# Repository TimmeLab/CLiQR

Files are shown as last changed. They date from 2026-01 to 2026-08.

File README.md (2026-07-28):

# CLiQR - Capacitive Lick Quantification in Rodents
### Created for the Timme Lab at University of Cincinnati
### Author: Christopher Parker

This repository contains the software for running our capacitive lickometry system, which records rodent licking behavior using MPR121 capacitive touch sensors connected via FT232H USB-to-I2C boards.

## System Overview

**CLiQR** provides a web-based GUI for data recording and Jupyter notebooks for data analysis:
- **recording_gui.py** - Standalone Solara web GUI for recording (primary interface)
- **DataAnalysis.ipynb** - Jupyter notebook for batch analysis and visualization
- **DataRecording.ipynb** - Legacy notebook interface (deprecated, kept for reference)

## Installation

### Windows Driver Setup

Before first use on Windows, you must install drivers for the FT232H boards using Zadig:
1. Download Zadig from https://zadig.akeo.ie/
2. Follow the steps outlined here: https://learn.adafruit.com/circuitpython-on-any-computer-with-ft232h/windows

### Software Installation

Clone this repository (or download and extract the .zip file).

**Option 1 - Miniforge (recommended for Windows):**

Download and install Miniforge: https://github.com/conda-forge/miniforge/releases

On Windows, use the "Miniforge Prompt" from the Start menu. On Mac/Linux, use your normal terminal. Then run:
```bash
conda env create --file environment.yml
conda activate cliqr
```

**Option 2 - pyenv-virtualenv (Unix-based systems):**

Install pyenv-virtualenv: https://github.com/pyenv/pyenv-virtualenv

Then run:
```bash
pyenv virtualenv 3.13 cliqr
pyenv activate cliqr
pip install -r requirements.txt
```

### Hardware Setup (One-Time Configuration)

The FT232H boards must be assigned serial numbers so the system can identify them consistently, even if USB ports end up being shuffled somehow. Connect boards **ONE AT A TIME** and run:

```bash
python set_ft232h_serial.py FT232H0
```

Repeat for each board, using serial numbers FT232H0 through FT232H3. These serial numbers map to sensors 1-24 as defined in `utils/state.py`. If you use different serial numbers, update the `SERIAL_NUMBER_SENSOR_MAP` constant.

## Running the System

### Data Recording

**Option 1 - Command Line:**
```bash
conda activate cliqr  # or: pyenv activate cliqr
solara run recording_gui.py
```

The GUI will open in your default web browser at http://localhost:8765

**Option 2 - Windows Desktop Shortcut:**

Hold Shift and right-click start_cliqr.bat, then select Send To -> Desktop (create shortcut). You can then rename the desktop shortcut as you wish, I have just called it "CLiQR." Double-click the shortcut to launch the GUI without using the command line. Note, this shortcut will only work if you used the miniforge3 installation instructions.

### Recording Workflow

1. **Initialize Hardware** - Click "Initialize Hardware" to detect and connect to FT232H boards
2. **Upload Layout File** - Drag and drop a layout CSV file mapping sensor positions to animal IDs (see `layouts/default_layout.csv` for format)
3. **Enter Animal Weights** - Enter weights in grams for each animal before recording
4. **Start Session** - Click "START RECORDING" to begin the recording session
5. **Start Individual Sensors** - Click START on each sensor card to begin recording for that animal
6. **Test Sensors** - Use the TEST button to view recent data and confirm sensors are working
7. **Enter Start Volumes** - After starting each sensor, enter the initial sipper volume in mL in the Start Vol box
8. **Stop Individual Sensors** - Click STOP when done recording each animal
9. **Enter Stop Volumes** - After stopping each sensor, enter the final sipper volume in mL in the Stop Vol box
10. **End Session** - Click "STOP RECORDING" to end the session and save all data to HDF5

**Important Notes:**
- All volume/weight data and any comments in the Comments box are written to the HDF5 file when you click "STOP RECORDING"
- Data is saved to the "Lickometry Data" directory by default
- Each session creates a timestamped HDF5 file: `raw_data_YYYY-MM-DD_HH-MM-SS.h5`

### Data Analysis

For batch analysis of recorded data:
```bash
conda activate cliqr
jupyter-lab
```

Open `DataAnalysis.ipynb` and follow the instructions to analyze multiple recording sessions.

## Layout File Format

Layout files map sensor numbers (1-24) to animal IDs. The file should be CSV format with no header:

```
1,A1
2,A2
3,A3
...
24,A24
```

A default template is provided at `layouts/default_layout.csv`.

## Troubleshooting

**"No FT232H boards found"**
- Check USB connections
- Verify libusbK drivers are installed (Windows) or libusb is installed (Unix-based)
- Try different USB ports or USB-C cables (not all USB cables are created alike!)

**Recording not starting**
- Ensure hardware is initialized first
- Check that layout file has been uploaded
- Verify output directory permissions

**Sensor shows no data**
- Use the TEST button to check if sensor is responding
- Check physical connections to MPR121 boards
- Ensure FT232H boards are in I2C mode (there is a small switch on the board)

For more details, see `DEPLOYMENT.md` and `TEST_MOCK_MODE.md`.

## System Architecture

The system supports 24 sensors arranged in a 4×6 grid (matching the physical rack layout):
- 4 FT232H boards (FT232H0-3)
- 4 MPR121 capacitive touch sensors (one per FT232H board)
- 6 sensors per board (using every other channel: 1, 3, 5, 7, 9, 11)

Data is recorded at approximately 100 Hz and saved in HDF5 format with the structure:
```
/board_{serial_number}/sensor_{sensor_id}/
    ├── cap_data       # Capacitance readings
    ├── time_data      # Timestamps
    ├── start_time     # Recording start timestamp
    ├── stop_time      # Recording stop timestamp
    ├── start_vol      # Initial sipper volume (mL)
    ├── stop_vol       # Final sipper volume (mL)
    └── weight         # Animal weight (g)
```

Multiple start/stop cycles per sensor are supported with numbered suffixes: `start_time1`, `start_time2`, etc.

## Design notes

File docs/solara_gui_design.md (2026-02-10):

# Solara GUI Design Document

## Overview

This document outlines the design for the Solara-based standalone GUI that replaces DataRecording.ipynb. The design maintains all existing functionality while improving usability for non-technical users.

## Design Principles

1. **Preserve Functionality**: No changes to data recording logic or HDF5 structure
2. **Simplify Access**: Remove JupyterLab dependency
3. **Match Physical Layout**: UI mirrors the physical rack arrangement
4. **Clear Visual Feedback**: Status indicators for all recording operations
5. **Error Prevention**: Disable invalid actions, warn before destructive operations

## Page Structure

```
┌─────────────────────────────────────────────────────────────┐
│                     CLiQR Recording System                   │
│                                                              │
│  ┌──────────────────────────────────────────────────────┐  │
│  │  Hardware Status                                     │  │
│  │  ● FT232H0: Connected (6 sensors)                   │  │
│  │  ● FT232H1: Connected (6 sensors)                   │  │
│  │  ● FT232H2: Connected (6 sensors)                   │  │
│  │  ● FT232H3: Connected (6 sensors)                   │  │
│  │  [Refresh Hardware]                                  │  │
│  └──────────────────────────────────────────────────────┘  │
│                                                              │
│  ┌──────────────────────────────────────────────────────┐  │
│  │  Session Controls                                    │  │
│  │  Output Directory: [____________] [Browse]           │  │
│  │  Layout File: [____________] [Upload CSV]            │  │
│  │  [START RECORDING]                                   │  │
│  │  Status: Idle | Recording since: --:--:--            │  │
│  └──────────────────────────────────────────────────────┘  │
│                                                              │
│  ┌──────────────────────────────────────────────────────┐  │
│  │  Sensor Grid (Rack Layout)                           │  │
│  │  ┌────┬────┬────┬────┬────┬────┐                   │  │
│  │  │ S1 │ S2 │ S3 │ S4 │ S5 │ S6 │  Shelf 1 (Top)    │  │
│  │  ├────┼────┼────┼────┼────┼────┤                   │  │
│  │  │ S7 │ S8 │ S9 │S10 │S11 │S12 │  Shelf 2          │  │
│  │  ├────┼────┼────┼────┼────┼────┤                   │  │
│  │  │S13 │S14 │S15 │S16 │S17 │S18 │  Shelf 3          │  │
│  │  ├────┼────┼────┼────┼────┼────┤                   │  │
│  │  │S19 │S20 │S21 │S22 │S23 │S24 │  Shelf 4 (Bottom) │  │
│  │  └────┴────┴────┴────┴────┴────┘                   │  │
│  └──────────────────────────────────────────────────────┘  │
│                                                              │
│  ┌──────────────────────────────────────────────────────┐  │
│  │  Activity Log                       [Clear Log]      │  │
│  │  [Scrollable text area showing operations]           │  │
│  └──────────────────────────────────────────────────────┘  │
│                                                              │
│  ┌──────────────────────────────────────────────────────┐  │
│  │  Comments                                             │  │
│  │  [Text area for session notes]                        │  │
│  │  (Auto-saved to HDF5 file on stop)                   │  │
│  └──────────────────────────────────────────────────────┘  │
└─────────────────────────────────────────────────────────────┘
```

## Sensor Card Design

Each sensor card contains all controls for one sensor:

```
┌──────────────────────────────────────┐
│ Sensor 1 [Animal: A1]          ●IDLE │  ← Status: IDLE/RECORDING/ERROR
├──────────────────────────────────────┤
│ [START]  Timer: 00:00  [TEST]       │
├──────────────────────────────────────┤
│ Start Vol:  [____] mL               │
│ Stop Vol:   [____] mL               │
│ Weight:     [____] g                │
└──────────────────────────────────────┘
```

### Sensor Card States

1. **IDLE** (Gray):
   - Before session starts or after sensor stopped
   - START button disabled if session not started
   - All inputs editable

2. **RECORDING** (Green):
   - During active recording
   - START button changes to STOP button
   - Timer updates every 60 seconds
   - Volume inputs disabled once recording starts

3. **ERROR** (Red):
   - Sensor disconnected or read failure
   - All controls disabled
   - Shows error message

## Component Hierarchy

```python
App()
├── HeaderCard()
│   └── Title, version info
├── HardwareStatusCard()
│   ├── BoardStatus() × 4 (one per FT232H)
│   └── RefreshButton()
├── SessionControlsCard()
│   ├── OutputDirectoryPicker()
│   ├── LayoutFileUpload()
│   ├── StartStopButton()
│   └── SessionStatus()
├── SensorGrid()
│   └── SensorCard() × 24
│       ├── SensorHeader()
│       ├── ControlButtons()
│       ├── Timer()
│       └── VolumeWeightInputs()
├── ActivityLog()
│   └── LogViewer()
└── CommentsCard()
    └── CommentsTextArea()
```

## Reactive State Structure

```python
# Global session state
@solara.reactive
def recording_all():
    return False

@solara.reactive
def filename():
    return ""

@solara.reactive
def output_directory():
    return os.getcwd()

@solara.reactive
def layout_df():
    return pd.DataFrame()  # Animal ID mapping

# Per-sensor state (24 instances)
class SensorState:
    is_recording: bool = False
    start_time: float = 0.0
    elapsed_seconds: int = 0
    start_volume: float = 0.0
    stop_volume: float = 0.0
    weight: float = 0.0
    status: str = "idle"  # idle, recording, error
    error_message: str = ""
    animal_id: str = ""

# Hardware state
@solara.reactive
def boards_connected():
    return {}  # {serial_number: num_sensors}

# Activity log
@solara.reactive
def log_messages():
    return []  # List of timestamped log entries

# Comments
@solara.reactive
def comments():
    return ""
```

## Key Interactions

### Starting a Recording Session

1. User clicks "START RECORDING"
2. System checks:
   - Output directory writable?
   - At least one board connected?
3. Generate filename with timestamp
4. Create HDF5 file
5. Enable all sensor START buttons
6. Start async recording task
7. Update button to "STOP RECORDING"

### Starting a Sensor

1. User clicks sensor's START button
2. Check session is active
3. Write start_time to HDF5
4. Change button to STOP
5. Start timer
6. Update status indicator to RECORDING (green)
7. Log "Sensor X started"

### Stopping a Sensor

1. User clicks sensor's STOP button
2. Write stop_time to HDF5
3. Write volumes and weight to HDF5
4. Stop timer
5. Update status indicator to IDLE (gray)
6. Log "Sensor X stopped (duration: HH:MM:SS)"

### Testing a Sensor

1. User clicks TEST button
2. Read last 250 samples from HDF5
3. Generate matplotlib plot
4. Display in modal dialog or separate area
5. Log "Sensor X tested"

### Stopping a Recording Session

1. User clicks "STOP RECORDING"
2. For each sensor still recording:
   - Automatically stop sensor
   - Save volumes/weights
3. Save comments to HDF5
4. Cancel async recording task
5. Log "Session ended - file saved: {filename}"
6. Disable all sensor controls
7. Update button to "START RECORDING"

## Color Scheme

```python
COLORS = {
    'primary': '#1976D2',      # Blue for main actions
    'success': '#4CAF50',      # Green for recording
    'warning': '#FF9800',      # Orange for warnings
    'error': '#F44336',        # Red for errors
    'idle': '#9E9E9E',         # Gray for idle
    'background': '#FAFAFA',   # Light gray background
    'card': '#FFFFFF',         # White cards
    'text': '#212121',         # Dark text
    'text_secondary': '#757575' # Gray secondary text
}
```

## Layout Dimensions

- **Sensor Card**: 250px × 200px
- **Sensor Grid**: 6 columns × 4 rows
- **Minimum Window Width**: 1600px
- **Activity Log Height**: 300px
- **Comments Height**: 150px

## Accessibility Features

1. **Keyboard Navigation**: All controls accessible via keyboard
2. **Visual Status**: Color + icon + text for status (not color alone)
3. **Large Click Targets**: Buttons minimum 40px height
4. **Clear Labels**: All inputs have associated labels
5. **Error Messages**: Clear, actionable error messages

## Deployment Considerations

### Running the App

```bash
# Development mode
solara run recording_gui.py

# Production mode (server accessible on network)
solara run recording_gui.py --host 0.0.0.0 --port 8000

# Windows shortcut (start_cliqr.bat)
@echo off
call conda activate cliqr
solara run recording_gui.py
pause
```

### File Structure

```
CLiQR-GUI/
├── recording_gui.py          # Main Solara app
├── components/               # Reusable UI components
│   ├── __init__.py
│   ├── sensor_card.py
│   ├── hardware_status.py
│   └── session_controls.py
├── hardware/                 # Hardware interface
│   ├── __init__.py
│   ├── ft232h.py            # FT232H initialization
│   └── mpr121.py            # MPR121 sensor interface
├── recording/               # Recording logic
│   ├── __init__.py
│   ├── recorder.py          # Async recording loop
│   └── hdf5_writer.py       # HDF5 file operations
└── utils/
    ├── __init__.py
    ├── state.py             # Reactive state definitions
    └── logging.py           # Activity log utilities
```

## Migration Strategy

1. **Phase 1**: Create basic Solara app with UI skeleton (no hardware)
2. **Phase 2**: Integrate hardware initialization and mock recording
3. **Phase 3**: Implement full recording loop with real sensors
4. **Phase 4**: Add testing, error handling, and polish
5. **Phase 5**: User testing and refinement

## Differences from Notebook

### Additions
- Hardware status indicator
- Output directory selection
- Visual status indicators (colored dots)
- Activity log with timestamps
- Modal dialogs for test plots

### Removals
- Graph area for inline plotting (moved to modal)
- Clear output/graph buttons (log auto-scrolls)
- Separate layout display (integrated into session controls)

### Changes
- Timer updates every 60s (same as notebook)
- Comments auto-saved on stop (same as notebook)
- Sensor arrangement matches physical rack (same as notebook)

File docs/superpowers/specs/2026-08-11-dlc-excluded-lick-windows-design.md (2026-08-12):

# Licks DLC never saw -> synced videos (`--dlc-exclude`)

Date: 2026-08-11
Status: approved, ready for implementation plan

## Problem

`--dlc-windows` (see `2026-08-11-dlc-sync-video-windows-design.md`) renders a clip for every stretch
where DeepLabCut says the animal was at the sipper. That answers "when the animal was drinking, did
the capacitance detector agree?"

The opposite question is the one that bounds the false-positive rate: **when the capacitance
detector reported licks, was the animal actually there?** Today nothing selects those stretches. The
default trace search picks the busiest bouts regardless of what the video shows, so its output is
dominated by real drinking and the suspicious blocks are buried.

We want the complement: bouts the detector found that fall in no DLC window, rendered as synced
clips so they can be adjudicated by eye.

## Solution overview

Add `--dlc-exclude PATH` to `scripts/find_interesting_windows.py` -- a third mode, mutually
exclusive with `--dlc-windows`.

The mode is **bout-seeded** (like the default trace search) but **DLC-filtered**: it reads the same
CSV `find_dlc_windows.py` writes, converts every window to session seconds, and then emits the
busiest detected bouts that touch none of them.

Which DLC CSV you pass is the strictness knob:

* a permissive presence CSV (no `--require-tongue`, loose `--max-nose-dist`) excludes anything where
  the animal was merely near the sipper, so what survives is licks reported while the animal was
  demonstrably elsewhere -- unambiguous false positives;
* a strict drinking CSV (`--require-tongue`) also lets through "at the sipper but not drinking",
  which is a real and separate failure mode worth looking at.

No new DLC gating logic: the thresholds live in `find_dlc_windows.py`, where they already are.

Everything downstream is unchanged -- the same `rois.csv` writer, the same `make_clips.sh` writer,
the same `make_sync_video.py` command shape.

## Data flow

1. `build_cycles_for_dlc(combined_h5, raw_map, animals)` -- reused unchanged. Per cycle: the filmed
   animal, `raw_h5`, `layout`, trace bounds, restart flag, `lick_times`.
2. New `dlc_exclusion_spans(dlc_rows, cycles, sess_loader=None)` ->
   `({stem: {"spans": [(start_s, end_s), ...], "coverage": (first_s, last_s)}}, skips)`.
   Rows are grouped by video so the per-frame session times are read once per recording, exactly as
   `build_dlc_rois` does. Conversion uses the same clock as the renderer:
   `load_frame_session_times(raw_h5)` then `frame_window_to_session(sess, start_frame, end_frame)`.
   `coverage` is `(sess[0], sess[-1])`.
   **No clamp to the trace.** `build_dlc_rois` clamps because it is about to render; here a window
   outside the trace still proves the animal was at the sipper, so clamping it away would leak a
   false-positive candidate.
3. For each cycle that has a usable exclusion entry, read that cycle's `cap_data`, `time_data`,
   `bout_start_times`, `bout_durations`, `bout_lick_counts`, `lick_times` for the **filmed animal
   only** (the other cages have no camera, so nothing can be adjudicated for them).
4. Drop disqualified bouts (rules below), then call the existing `build_rois_for_cycle` with the
   surviving bout arrays and `n_climb=0`. Climbing windows are not lick false positives.
5. Relabel each returned region `category="no_dlc"` and attach the usual provenance
   (`animal`, `cycle`, `filmed`, `restart`, `raw_h5`, `layout`).
6. `write_outputs(all_rows, args)` -- unchanged.

The only genuinely new code is step 2 and the bout filter in step 4. Frame -> session time is not
re-derived here; see the `--dlc-windows` design for why the sidecar clock, not `frame / fps`, is the
only correct conversion.

## Disqualification rules

A bout occupies `[bout_start, bout_start + bout_duration]`. It is kept only if **both** hold:

* **Inside DLC coverage.** The bout lies within the video's `coverage` span. The trace can start
  before the camera and run past it; outside the video DLC saw nothing, so the absence of a window
  there is not evidence of anything.
* **No overlap with any guarded span.** Each DLC span is grown by `--dlc-guard` seconds (default
  1.0) on both sides; any intersection with any grown span disqualifies the bout.

The guard band exists because DLC window edges are ragged -- they come out of `--merge-gap`,
`--min-frames` and `--pad` in `find_dlc_windows.py`, so a window's boundary is not the moment the
animal arrived or left. Without a guard, bouts that start a few hundred milliseconds before a window
opens survive and are almost all real licks.

The test is applied to the **bout**, not to the padded clip window. The clip is deliberately wider
(`--lick-pad` of context each side), and a clip that happens to show the edge of a DLC window is
useful context, not a disqualification.

## Skips

Nothing is silently dropped. Skips are counted by reason and printed at the end, in the style of
`print_dlc_skips`.

Whole-cycle skips (the cycle emits nothing):

| Reason | Why |
|---|---|
| `no_dlc_video` | No CSV row names this cycle's recording, **or** rows do name it but every single one failed to convert to a session-time span (see `frame_out_of_range` below). "DLC found no windows", "DLC never ran on this video" and "DLC ran but nothing it wrote is usable" are all indistinguishable from the caller's side, and any of them would dump the cycle's entire bout list into the false-positive pile if treated as "zero exclusion spans". `dlc_exclusion_spans` counts the second case itself (per video, the same unit as `cfr_video`/`no_cycle`/`no_video_times`); the driver counts the first. |
| `cfr_video` | The video is a `_cfr` re-encode; its frame indices are not guaranteed to be the original container's, so no span can be placed on the session clock. |
| `no_cycle` | A CSV video with no matching cycle in the combined file (or filtered out by `--animals`). Counted against the rows, as in `--dlc-windows`. |
| `no_video_times` | The recording's mp4 or PTS sidecar is missing on this machine, so frames cannot be timed. |
| `no_trace` | The filmed animal cannot be resolved, or its group has no usable `time_data` -- **or** the group exists with usable `time_data` but predates the bout-array outputs (an older analysis pipeline never wrote `bout_start_times`/`bout_durations`/`bout_lick_counts`). Two different causes, one reason: the printed explanation names both so a reader is not sent hunting layout/video-sensor resolution when the real cause is a stale combined file. |

Per-bout skips:

| Reason | Why |
|---|---|
| `outside_video` | The bout falls outside the video's coverage span. |
| `in_dlc_window` | The bout intersects a guarded DLC span -- i.e. DLC agrees the animal was there. |

Per-row skip, when converting a DLC window to a span:

| Reason | Why |
|---|---|
| `frame_out_of_range` | `start_frame` is negative or past the end of the PTS sidecar. |

`no_dlc_video` is the correctness crux of this mode and is called out explicitly in the printed
summary.

Per-cycle evidence, not just skip counts: `no_dlc_video` only fires when a cycle has NO usable DLC
spans at all. A cycle that has one or two spans, against which nearly every bout survives, passes
that guard cleanly and still produces a misleading false-positive pile -- one DLC window over a
multi-hour session is barely more informative than zero. `run_dlc_exclude_mode` therefore also
returns a `cycle_reports` list (one entry per searched cycle: `n_spans`, `n_bouts`, `n_kept`,
`restart`), and `print_dlc_exclude_skips` prints a line per cycle plus a `WARNING` when a cycle has
few spans (`<= 2`) AND a near-total kept fraction (`>= 90%`) -- see
`DLC_EXCLUDE_THIN_EVIDENCE_MAX_SPANS`/`DLC_EXCLUDE_THIN_EVIDENCE_MIN_KEPT_FRACTION` in
`scripts/find_interesting_windows.py` for the exact thresholds and their rationale. This does not
change which bouts are selected -- it is a reporting-only signal for the human adjudicating the
output.

## Clock assumption for restart recordings

DLC spans come from the session clock (`load_frame_session_times`/`SessionClock`, anchored to the
recording's own PTS sidecar); bout times come from the combined file's clock (`filter_data`'s
per-cycle rebasing). For a plain single-cycle recording the two agree, because both trace back to
the same `filter_data` call. `--dlc-windows` never has to care whether they agree, because a DLC
window IS the renderer's own reference frame -- it is never compared against anything else. This
mode is different: it directly compares a DLC span against a bout's start/end time on what has to
be the SAME clock for the comparison to mean anything.

For a RESTART recording (operator stopped and restarted within one raw file), the module docstring
already documents a known history of the two clocks disagreeing by a fixed offset (~280 s was
observed for the 2026-07-22 recording). A silent disagreement here would convert real drinking into
a reported "false positive" (bout looks outside every DLC span, because the spans are shifted) and
hide genuine ones -- and it would do so with no visible symptom: `coverage` comes from the PTS
sidecar and is typically far wider than the trace (observed `(-604.5, 7682.8)` against a `(0, 7200)`
trace for the 2026-07-22 recording), so `outside_video` cannot catch a shift of a few hundred
seconds the way it would catch a shift of hours.

We do not correct for this automatically, for the same reason the module docstring gives for
`--offset`/`--sync-offset`: getting a silent correction subtly wrong is worse than not correcting.
Instead there is a cheap manual check: a restart cycle's spans should contain MOST of its
`lick_times`, since DLC and the detector are both looking at the same drinking. This was checked by
hand for the current dataset's one restart cycle (2026-07-22, cycle 0): 663/922 licks fall inside
spans at shift 0, and 0/922 at either +-280.33 s (the known offset), so the two clocks resolve this
cycle the same way and no correction is needed today. This is a point-in-time check, not something
re-verified automatically per run -- a future restart recording's `--dlc-exclude` output should be
sanity-checked the same way before being trusted. `cycle_reports` marks restart cycles so
`print_dlc_exclude_skips` can flag them inline (see above) without a second reporting mechanism; the
per-clip restart WARNING `build_command` already emits addresses rendering only (`--offset` is
applied after selection), so it cannot fix a mis-selected clip set and is not a substitute for this
check.

## Known limitation

A bout where the animal really was drinking but DLC missed it -- likelihood never cleared
`--pcutoff`, or the tongue never crossed `--tongue-pcutoff` -- still lands in the output. That is
intended: the clips are a review queue and the human adjudicates. Stricter gating in the input CSV
produces more such rows; that is the trade-off the choice of CSV controls.

## CLI

```
python scripts/find_interesting_windows.py "Lickometry Data/results_combined_ACG-26-3_*.h5" \
    --dlc-exclude second_iteration_windows_with_tongue.csv \
    --dlc-guard 1.0 --n-lick 5 \
    --csv fp_rois.csv --sh make_fp_clips.sh --speed 0.25
```

* `--dlc-exclude PATH` -- CSV written by `dlc_integration/find_dlc_windows.py`. Enables the mode.
* `--dlc-guard SECONDS` -- guard band around each DLC window (default 1.0). `0` disables it.
* Passing `--dlc-exclude` together with `--dlc-windows` is a `parser.error`: they select windows by
  opposite criteria and there is no sensible combination.
* Honoured: `--n-lick` (bouts per cycle, busiest first), `--roi-seconds`, `--lick-pad`, `--csv`,
  `--sh`, `--out-dir`, `--animals` (filters on the resolved filmed animal), `--raw-map`, `--offset`,
  `--speed`.
* Unused (passing one is not an error): `--n-climb` (forced to 0), `--var-window`, `--min-var`,
  `--climb-skip-edges`, `--include-controls` -- the filmed animal is never a control cage.

## Output

The existing `CSV_COLUMNS`, with:

* `category` = `"no_dlc"`,
* `rank` = 0-based within the cycle, busiest surviving bout first,
* `score` = the bout's lick count,
* `n_licks_in_window` = licks inside the emitted window, as elsewhere.

Clips are named `<animal>_c<cycle>_no_dlc<rank>.mp4` by the existing `build_command`. Restart-cycle
WARNING comments are emitted unchanged.

`no_dlc` clips are rendered with `--no-crop`, showing the full frame. The crop box is framed tightly
on the sipper tip to make the tongue visible during licking; a `no_dlc` clip exists precisely to
show where the animal WAS instead, which is outside that box, so cropping would hide the very
evidence the clip exists to demonstrate.

## Testing

All in `tests/test_find_interesting_windows.py`, with an injected `sess_loader`, so no recording or
video is needed on disk.

* `dlc_exclusion_spans` converts frames to session seconds and does **not** clamp to the trace.
* Each whole-video skip reason is counted: `cfr_video`, `no_cycle`, `no_video_times`, `no_trace`.
* `frame_out_of_range` is counted per row.
* Guard band: a bout ending 0.5 s before a DLC window is dropped at `--dlc-guard 1.0` and kept at
  `--dlc-guard 0`.
* Coverage: a bout after `coverage[1]` is skipped as `outside_video`.
* A cycle with no rows in the CSV emits nothing and is counted `no_dlc_video`.
* A cycle whose video HAS rows but every one fails conversion (`frame_out_of_range`) also produces
  no searchable entry and is counted `no_dlc_video`, never searched against an empty spans list --
  the regression this whole-branch review caught.
* Two video path strings resolving to the same recording stem accumulate spans rather than the
  second overwriting the first.
* `run_dlc_exclude_mode`'s `cycle_reports`: `n_kept` counts every surviving bout, not just the
  `--n-lick` emitted rows; `print_dlc_exclude_skips` prints a per-cycle line and a thin-evidence
  `WARNING` when spans are few and the kept fraction is near 1.0, and marks restart cycles inline.
* End to end: a bout inside a DLC window is absent from the output; a bout far from every window is
  present with `category="no_dlc"`, the right `rank`, `score` and `n_licks_in_window`.
* `--dlc-exclude` with `--dlc-windows` exits non-zero.

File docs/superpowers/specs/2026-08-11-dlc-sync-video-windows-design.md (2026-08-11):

# DLC windows -> synced videos (`--dlc-windows`)

Date: 2026-08-11
Status: approved, ready for implementation plan

## Problem

`dlc_integration/find_dlc_windows.py` already finds the stretches of a session video where the
animal is confidently at the sipper (and, with `--require-tongue`, actually drinking). It writes one
row per window to a CSV. Those windows are exactly the ones worth reviewing as side-by-side
video + capacitance clips, but today the only way to get such a clip is
`scripts/find_interesting_windows.py`, which finds its own windows from the capacitance trace
(busiest bouts, high-variance non-bout stretches) and knows nothing about DLC.

The two selections disagree by construction: DLC gates on pose, the trace search gates on
capacitance. Reviewing the DLC windows in a synced clip is how we see whether the capacitance
detector agreed with what the animal was actually doing.

The DLC *labeled* videos (`create_labeled_video` output) are not involved. We only read the CSV and
render from the original recording, so the clip shows the raw footage next to the trace.

## Solution overview

Add `--dlc-windows PATH` to `scripts/find_interesting_windows.py`. When given, the script runs in
**pure DLC mode**: it does not search the trace at all; every emitted region comes from a row of the
DLC CSV, converted from video frame indices into session seconds.

Everything downstream is unchanged -- the same `rois.csv` writer, the same `make_clips.sh` writer,
the same `make_sync_video.py` command shape.

## CLI

```
python scripts/find_interesting_windows.py <combined_h5> \
    --dlc-windows second_iteration_windows_with_tongue.csv \
    --csv dlc_rois.csv --sh make_dlc_clips.sh --speed 0.25
```

* `--dlc-windows PATH` -- CSV written by `dlc_integration/find_dlc_windows.py`.
* The `combined_h5` positional stays **required**. It supplies:
  * the per-cycle `raw_h5` / `layout` provenance attributes,
  * the filmed animal (via `resolve_filmed_animal`),
  * the trace the emitted commands read through `--combined-h5` / `--cycle`,
  * `lick_times`, used to annotate each DLC window with how many detected licks fall inside it.
* Ignored in DLC mode (they only parameterise the trace search): `--n-lick`, `--n-climb`,
  `--roi-seconds`, `--lick-pad`, `--climb-skip-edges`, `--var-window`, `--min-var`. Passing one
  alongside `--dlc-windows` is not an error; the value is simply unused.
* Still honoured: `--csv`, `--sh`, `--out-dir`, `--animals`, `--raw-map`, `--offset`, `--speed`.
  `--animals` filters on the resolved (filmed) animal of each mapped video.
* Also unused in DLC mode: `--include-controls`. A DLC row's animal is the cycle's filmed animal,
  which is never a control cage.
* No new pass-through flags for `make_sync_video` (`--window`, `--sync-offset`, `--fps`,
  `--keep-intermediate`). `--speed` already passes through and is enough.

## Frame -> session time

This is the only genuinely new computation.

A DLC row's `start_frame` / `end_frame` are half-open indices into the **original container**
(`Frames2plot=range(start, end)`), and its `start_sec` / `end_sec` columns are just `frame / fps` --
video-file time, which is NOT the reference `make_sync_video --start/--end` expect (session seconds
since the Start bookmark). Convert with exactly the clock the renderer uses to place frames:

```python
anchor = read_video_anchor(raw_h5)
video, pts_txt = resolve_paths(raw_h5, anchor)
pts_ns = np.loadtxt(pts_txt, dtype=np.int64)
clock = session_clock(anchor, pts_ns)                       # latency + drift slope
sess = frame_session_times(clock, load_container_pts(pts_txt, pts_ns))
start_s = sess[start_frame]
end_s = sess[end_frame - 1]        # end_frame is EXCLUSIVE in the DLC CSV
```

`load_container_pts` (imported from `make_sync_video`) prefers the Pi's `<stem>.encpts.txt`, which
has one line per ENCODED frame, so encoder drops are already excluded and container ordinal `k`
indexes it directly. Falling back to the capture sidecar `<stem>.txt` is what
`make_sync_video` does for recordings made before drop-marking, so the two stay consistent.

Because the window is derived from the same `SessionClock` and the same sidecar that
`make_sync_video` uses to time frames, the frames DLC scored are the frames the clip shows. Do not
recompute this from `start_sec` and a nominal fps: the sidecar clock drifts against the container's
constant rate by seconds over a session (see `docs/video-sync-alignment-bugs.md`).

`resolve_paths` / `read_video_anchor` are called ONCE per video (per cycle), not per row.

## Row -> cycle mapping

DLC CSV rows carry a `video` path (often a cluster path that does not exist locally), never the raw
`.h5`. Map by basename:

1. `basename(row["video"])` -> stem, e.g. `raw_data_2026-07-24_12-02-14_cfr.mp4` ->
   `raw_data_2026-07-24_12-02-14_cfr`.
2. Strip one trailing `_cfr` -> `raw_data_2026-07-24_12-02-14`.
3. Match against `basename(raw_h5)` without extension, for every cycle in the combined file (the
   `raw_h5` attribute, or the `--raw-map` fallback).

Verified against the current data: the combined file's cycles 0-5 are the 07-22 .. 07-29
recordings, and `second_iteration_windows.csv` rows for those dates map cleanly.

The animal for a mapped row is that cycle's filmed animal. Rows are grouped by video so each
video's anchor/pts work happens once.

## Skips

Nothing is silently dropped: every skip is counted by reason and the counts are printed at the end.

| Case | Granularity | Why |
|---|---|---|
| stem ended in `_cfr` | whole video | The `_cfr.mp4` files are re-encodes; their frame indices are not guaranteed 1:1 with the original container (`-fps_mode cfr` drops ~1 frame per 25k), so a frame index cannot be trusted as a container ordinal. Those sessions (07-13/14/16/21) also have no local mp4 or pts sidecar, so no clip could be rendered anyway. |
| no matching cycle in the combined file | whole video | Nothing to read a trace from. |
| `raw_h5`, mp4, or pts sidecar missing on disk | whole video | `make_sync_video` could not run. |
| `start_frame >= len(sess)` | single row | Frame index past the end of the sidecar. |
| window entirely outside the cycle's `time_data` span | single row | Nothing to plot. |
| window partially outside that span | single row, clamped | Keeps the clip inside the trace, same as the trace-search path's `clip_window`. |

One more group-level skip, `no_trace`: if the cycle has no trace to draw -- because its filmed
animal cannot be resolved (`resolve_filmed_animal` returns `None`, e.g. the layout does not name
the video sensor), or that animal's group has no usable `time_data` -- the whole video's rows are
skipped under their own reason.

That reason exists to keep the report honest. Such a cycle carries `first_s == span_s == 0.0`, so
without it every one of its windows would fail the clamp and be counted as "the window falls
outside the cycle's trace" -- pointing the reader at DeepLabCut when the actual fault is animal or
layout resolution.

## Output

DLC regions are ordinary ROI dicts, so `write_csv` and `write_shell_script` are untouched:

| field | value in DLC mode |
|---|---|
| `category` | `"dlc"` |
| `rank` | 0-based row order within the (animal, cycle), following CSV order |
| `start` / `end` | converted session seconds, clamped to the trace span |
| `center` | midpoint of `start` / `end` |
| `score` | the row's `tongue_rate` (0.0 when the column is empty) |
| `n_licks_in_window` | detected licks inside the window, from the cycle's `lick_times` |

`CSV_COLUMNS` does not change.

Windows are used **as-is**: `find_dlc_windows.py --pad` already added context, and no cap is applied
(the upstream `--require-tongue` / `--min-frames` filters are where selection belongs). A 184-row
CSV yields up to 184 commands.

Clips keep the crop -- the DLC gate is nose-near-sipper, i.e. the same footage the licking clips
want, where the crop is what makes the tongue visible. Only `category == "climb"` gets `--no-crop`,
which DLC mode never produces. Output names come from the existing `build_command`:
`{animal}_c{cycle}_dlc{rank}.mp4`.

The restart-recording WARNING comment still fires, but its ADVICE differs by mode. A DLC window's
start/end are derived from the video clock, which is already `make_sync_video`'s reference, so
`--offset CYCLE=SECONDS` is the wrong remedy here: it shifts start and end together and would move
the clip off the DLC window entirely, while doing nothing about a trace/video mismatch. The DLC
warning therefore points at `make_sync_video --sync-offset` instead. Trace mode's wording is
untouched.

## Testing

New tests in `tests/test_find_interesting_windows.py`, all against pure functions with synthetic
inputs (no recordings, no ffmpeg):

* frame -> session conversion matches `frame_session_times` for a clock with latency and a drift
  slope != 1.0.
* `end_frame` is treated as exclusive: a row `[10, 20)` ends at `sess[19]`.
* stem -> cycle matching works with and without the `_cfr` suffix, and returns nothing for an
  unknown stem.
* a `_cfr` video is skipped as a group and counted.
* a video with no matching cycle, and one whose pts sidecar is absent, are each skipped and counted.
* a row whose `start_frame` exceeds the sidecar length is skipped; a row overlapping the end of the
  trace is clamped.
* a DLC row builds a command that keeps the crop (no `--no-crop`) and carries `--speed` when set.
* DLC mode emits no `lick` or `climb` rows.

## Non-goals

* No changes to `dlc_integration/find_dlc_windows.py` or its CSV schema.
* No use of the DLC labeled videos.
* No re-running of DLC inference, lick detection, or `filter_data`.
* No support for rendering `_cfr` sessions; if that is ever wanted, the fix is to re-run DLC on the
  original mp4 (as was already done for 07-22 onward), not to guess a frame mapping.

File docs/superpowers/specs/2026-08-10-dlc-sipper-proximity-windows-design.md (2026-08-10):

# DLC window selection: sipper proximity + tongue rhythmicity

**Date:** 2026-08-10
**Status:** design approved, not yet implemented
**Touches:** `dlc_integration/find_dlc_windows.py`, `dlc_integration/extract_outliers.py`
(one call site), `tests/test_dlc_windows.py` (new)

## Problem

`find_dlc_windows.py` decides "the mouse is here, render this window" from a single test:
`nose.likelihood >= --pcutoff`. That is too permissive. A confident nose anywhere in the frame
qualifies — the animal wandering past the sipper, sitting in the corner, or grooming produces
windows we then spend GPU-hours labeling and human time reviewing.

The DLC model now predicts four keypoints along the curve of the sipper tip
(`sipper_top`, `sipper_midtop`, `sipper_midbottom`, `sipper_bottom`), plus `nose`, `tongue`, `jaw`.
Those sipper keypoints let us ask the question we actually care about: *is the nose confidently
detected AND close to the sipper?* And, optionally, *is the tongue appearing rhythmically*, which is
what licking looks like in the likelihood trace (the tongue is only visible at the top of each lick,
so its likelihood pulses rather than staying high).

## Measurements that drove the design

Probed all ten `*snapshot_best-140*.h5` files in
`Lickometry Data/ACG-26-3/dlc_analysis_results/`:

- **Sipper keypoints are near-static within a session.** Each clears likelihood 0.8 in 77–99% of
  frames, and over those frames the per-keypoint position IQR is 0.5–3.5 px. A per-session median
  is effectively exact.
- **Sipper size varies between sessions.** Polyline arc length through the four points runs
  140–165 px (camera distance differs per recording). A pixel threshold therefore does not transfer
  between sessions; a threshold expressed as a fraction of that arc does.
- **Proximity is a real filter.** The nose clears 0.8 in only 0.3–2.4% of frames, and of those, the
  fraction within ~0.6 arc of the sipper ranges from 34% to 90% depending on the session.
- **Tongue rhythm separates cleanly.** In near-sipper stretches of the 07-22 session, drinking
  stretches show a 7.9–9.1 Hz spectral peak in `tongue.likelihood` and 3.4–7.8 upward crossings of
  0.6 per second; non-drinking stretches show 0–0.4 crossings/s and no lick-band peak. Counting
  crossings is enough — no FFT required.
- **Tongue detection is not trustworthy session-wide.** The 07-23 session has 18,442 frames with
  `tongue.likelihood > 0.6` yet almost none of them fall in a rhythmic near-sipper stretch. This is
  why the tongue test is opt-in, not part of the default gate.

Prototype run of the design below, per session, windows / total seconds:

| session | current (nose only) | + proximity | + tongue rhythm |
|---|---|---|---|
| 07-13 | 95 / 146.5 s | 26 / 67.3 s | 14 / 33.8 s |
| 07-14 | 39 / 75.5 s  | 13 / 37.2 s | 5 / 12.8 s |
| 07-16 | 31 / 72.1 s  | 13 / 34.4 s | 10 / 30.3 s |
| 07-21 | 30 / 86.8 s  | 9 / 53.3 s  | 6 / 48.9 s |
| 07-22 | 56 / 188.8 s | 27 / 122.8 s | 9 / 86.6 s |
| 07-23 | 99 / 178.5 s | 35 / 61.2 s | 1 / 9.7 s |
| 07-24 | 44 / 129.2 s | 17 / 73.5 s | 13 / 71.9 s |
| 07-27 | 44 / 112.7 s | 17 / 61.5 s | 13 / 58.3 s |
| 07-28 | 53 / 97.7 s  | 18 / 38.1 s | 3 / 14.6 s |
| 07-29 | 22 / 53.8 s  | 9 / 14.5 s  | 6 / 12.6 s |

(`--max-nose-dist 0.6`, all other parameters at their current defaults.)

## Design

### 1. Read coordinates, not just likelihood

`load_dlc_h5` currently returns `(scorer, bodyparts, likelihood_dict)` and discards x/y. It changes
to return `(scorer, bodyparts, coords)` where `coords[bodypart]` is a dict with keys `x`, `y`,
`likelihood`, each a float array of length n_frames. Both the pandas path and the h5py/pytables
fallback populate all three; the fallback already reads every column, it just filters to
`likelihood` today.

All existing callers within the file are updated. `extract_outliers.py` imports the module but has
its own reader (`load_predictions`, which already returns Nx3 x/y/likelihood arrays), so it is
unaffected by this change; `dlc_label_window.py` does not import either. The two readers stay
separate — merging them is a bigger refactor than this work justifies.

### 2. Sipper anchor

New `sipper_anchor(coords, bodyparts, pcutoff, min_frames=100)`:

- For each of `sipper_top`, `sipper_midtop`, `sipper_midbottom`, `sipper_bottom` present in the
  file, take frames where that keypoint's likelihood `>= pcutoff` (`--sipper-pcutoff`, default 0.6)
  and return the median (x, y) over them.
- A keypoint with fewer than `min_frames` confident frames is dropped from the polyline.
- Returns `(points, arc_length)` where `points` is the surviving keypoints **in anatomical order**
  (top → midtop → midbottom → bottom, not sorted by position) and `arc_length` is the sum of the
  segment lengths between consecutive surviving points.
- Fewer than two surviving points raises `ValueError("<path>: no usable sipper keypoints ...")`.

Ordering is anatomical because the polyline models the physical curve of the tip; re-sorting the
points would connect them in the wrong sequence when the sipper is oriented diagonally in frame.

### 3. Nose-to-sipper distance

New `point_to_polyline_distance(px, py, points)`: for each consecutive pair of points, compute the
standard vectorized point-to-segment distance (project onto the segment, clamp the parameter to
[0, 1], take the Euclidean distance to the clamped foot); return the elementwise minimum over
segments. Degenerate zero-length segments fall back to the distance to the shared endpoint.

Segment distance rather than nearest-keypoint distance, because adjacent keypoints are ~40–50 px
apart and a nose resting midway between two of them reads as up to ~25 px farther away than it is.

### 4. The gate

`find_windows` takes a boolean per-frame mask instead of `(likelihood, pcutoff)`; thresholding moves
out to the callers. The caller here (`rows_for_file`) builds:

```
thr  = args.max_nose_dist_px  if args.max_nose_dist_px is not None
       else args.max_nose_dist * arc_length
mask = (nose.likelihood >= args.pcutoff) & (nose_dist <= thr)
```

with `--max-nose-dist` defaulting to 0.6 (fraction of arc). `--max-nose-dist 0` and no
`--max-nose-dist-px` disables the proximity term entirely, reproducing today's behavior exactly.
`--max-nose-dist-px` (default None) overrides the fraction with a raw pixel threshold.

Everything downstream of the mask — merge by `--merge-gap`, drop by `--min-frames` and
`--min-confident`, pad by `--pad`, re-merge, split by `--max-frames` — is unchanged. `--bodypart`
stays and still names the keypoint whose likelihood and position are tested, so the gate can be
pointed at `jaw` instead of `nose` if that ever proves more reliable.

The other caller of `find_windows` is `extract_outliers.gate_mask`, which passes a likelihood array
today. It is updated to pass `arrays[args.gate_bodypart][:, 2] >= args.gate_pcutoff` — its behavior
is unchanged, and it does not gain proximity gating in this work (its `--windows-csv` path already
lets it replay the proximity-gated windows this script writes).

### 5. Tongue rhythmicity

New `tongue_upcross_rate(tongue_likelihood, start, end, pcutoff, fps)`: count upward crossings of
`pcutoff` within `[start, end)` (`np.diff` of the boolean-as-int8 mask equal to +1) and divide by
the window duration in seconds. A window that begins already above the cutoff contributes no
crossing for that leading run — an accepted small undercount, immaterial at 3+ crossings/s.

Applied **after the min-frames / min-confident filters but before padding and splitting**, so the
rate describes the detected behavior rather than the context padding, and so a long bout that later
gets split into chunks is judged as one bout.

- `--tongue-pcutoff` (default 0.6), `--tongue-min-rate` (default 3.0 crossings/s).
- `--require-tongue` (flag, default off) drops windows below the rate.
- The rate is **always computed and written to the CSV**, filtered only when the flag is set. One
  unfiltered run therefore tells you what threshold to use on the next. A CSV row inherits the rate
  of the pre-pad window it came from (the maximum, if padding merged several), rather than a rate
  recomputed over the padded row — padding is quiet by construction and would bias the number
  downward, misleading exactly the threshold-tuning the column exists for.
- If the file has no `tongue` bodypart, the column is empty and `--require-tongue` raises
  `ValueError` naming the available bodyparts.

### 6. CSV and summary

`CSV_FIELDS` gains three columns, appended after `mean_likelihood` so existing column order is
preserved:

- `mean_nose_dist` — mean distance in px over the frames in the window that pass the near mask;
  empty when proximity is disabled.
- `min_nose_dist` — minimum distance in px over the same frames; empty when disabled.
- `tongue_rate` — upward crossings per second, as defined above.

Distances are reported in pixels even when the threshold was given as a fraction, because pixels are
what you can check against a labeled frame. `sipper_scale` (arc length, px) and `nose_dist_thresh_px`
go into the per-file `--summary-json` record.

Because `CSV_FIELDS` changes, `--append` onto a CSV written by the current version raises the
existing missing-column error at `read_existing_csv`. That is the correct outcome — the old rows
have no distance data — and the error message already tells the user to use a new `--csv`.

The per-file stderr progress line reports frames passing the full gate, not just the likelihood
test, plus the arc length and threshold in px.

### 7. Testing

New `tests/test_dlc_windows.py`, pure-numpy, no DLC or video fixtures:

1. `point_to_polyline_distance` against hand-computed values: a point perpendicular to a segment's
   interior, a point beyond an endpoint (clamps to the endpoint), a point exactly on the polyline
   (0.0), and a degenerate zero-length segment.
2. `sipper_anchor` on synthetic arrays: median ignores low-likelihood outlier frames; a keypoint
   with too few confident frames is dropped; arc length matches the hand-summed segment lengths;
   anatomical ordering preserved when the keypoints are diagonal; fewer than two usable points
   raises.
3. `tongue_upcross_rate` on a square wave of known period → known rate; all-below → 0.0;
   all-above → 0.0; leading partial run does not count.
4. Gate equivalence: with `--max-nose-dist 0`, `find_windows` returns exactly the windows the
   likelihood-only mask produces on the same synthetic likelihood array.
5. Proximity actually excludes: a synthetic session with a confident nose far from the sipper for
   one stretch and near it for another yields only the near stretch.
6. `extract_outliers.gate_mask` still produces the same mask it does today for a given likelihood
   array and `--gate-pcutoff`, after the signature change.

## Out of scope

- Spectral (FFT) rhythmicity detection. Upward-crossing rate separates the measured data cleanly and
  is one line to explain in the paper; the FFT variant also flagged one window that had almost no
  confident tongue frames.
- Per-frame sipper tracking. The keypoints move by ~1–3 px within a session; a static per-session
  median is more robust than tracking through the 1–23% of frames where a keypoint drops out.
- Proximity or tongue gating inside `extract_outliers.py` (it only gets the one-line call-site fix),
  and any change to `dlc_label_window.py`, the SLURM scripts, or
  `scripts/find_interesting_windows.py` (the capacitance-trace ROI tool, which is unrelated).
- Unifying the two prediction readers (`find_dlc_windows.load_dlc_h5` and
  `extract_outliers.load_predictions`).
- Re-running DLC inference or cutting video.

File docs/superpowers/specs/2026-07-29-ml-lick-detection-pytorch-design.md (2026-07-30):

# ML Lick Detection — MATLAB → PyTorch Port + Transfer Learning

**Date:** 2026-07-29
**Status:** Approved design, ready for implementation planning

## Problem

Lick detection currently uses a threshold scanner (`basic_algorithm` in `data_analysis.py`,
a numpy port of the original MATLAB `lickDetector`). A separate MATLAB project
(`ML Detection MATLAB Code/`) trains a two-stage 1-D CNN cascade that detects licks more
robustly. We want that cascade available in the Python/CLiQR pipeline.

The saved MATLAB networks (`lickNets.mat`) were trained on capacitance data collected
**before** the MPR121 charge/discharge time (CDT) was increased. Raising CDT greatly
increased the magnitude (deflection depth) of the capacitance signal. The *shape* of a lick
deflection is essentially unchanged, but the amplitude scale is not — and the networks bake in
a **single global zscore normalization scalar** (netBout mean −5.00 / std 8.97; netPoint mean
−6.87 / std 8.22 — verified against `net.Layers(1).Mean` in MATLAB during the Task 3 parity gate;
note the MATLAB `#refs#` group letters C/c do NOT follow the naive uppercase=bout convention) fit
to the old scale. Those constants are now wrong for new recordings.

Because the deflection shape is preserved, **transfer learning** (reuse the trained
convolutional/FC weights, refit normalization, fine-tune) should adapt the networks to the new
data efficiently, rather than retraining from scratch. We assume we will label additional
high-CDT training data.

**CDT cutoff date: 2026-07-22.** Recordings on 2026-07-22 and onward are in the new (high) scale;
earlier recordings are old-scale. This date splits the corpus into fine-tune data (new-scale) and
old-scale validation oracles.

## Goals

- Reproduce the MATLAB two-net cascade **exactly** in PyTorch (so the ported weights are
  meaningful).
- Port the trained weights from `lickNets.mat` into the PyTorch models.
- Adapt to new high-CDT data via transfer learning: refit zscore normalization + fine-tune all
  layers at low learning rate.
- Provide a Python labeling tool (Panel; see labeler note below) to curate new training data, seeded by the existing
  threshold detector.
- Expose ML detection through the existing `filter_data(..., algorithm='ml')` flag, writing the
  same per-animal HDF5 datasets so downstream analysis is unchanged.

## Non-goals

- Replacing the threshold detector as the default (stays `basic_threshold`; ML is opt-in via the
  flag, may become default or be combined later).
- Bit-identical retraining of the MATLAB networks (we fine-tune; architecture is exact, weights
  become new).
- GPU training (networks and data are tiny; CPU is sufficient).
- Any change to the recording GUI or downstream plotting.

## Background: the MATLAB cascade (what we are reproducing)

Signal is resampled to **100 Hz** and each analysis window is offset so `max = 0`
(`y - max(y)`; deflections go negative).

**netBout** — coarse gate. Input = whole 3 s window (300 samples). Question: is there ≥1 lick in
the central 1 s?

```
imageInput[1x300x1], zscore (scalar mean/std)
conv2d[1x15]x16, pad same -> batchnorm -> relu
maxpool[1x4] stride[1x4]
conv2d[1x15]x32, pad same -> batchnorm -> relu
fullyConnected(32) -> relu -> fullyConnected(2) -> softmax
```

**netPoint** — fine classifier. Input = 21 samples (0.21 s). Question: is the center sample a
lick?

```
imageInput[1x21x1], zscore (scalar mean/std)
conv2d[1x5]x16, pad same -> batchnorm -> relu
conv2d[1x5]x32, pad same -> batchnorm -> relu
fullyConnected(32) -> relu -> fullyConnected(2) -> softmax
```

MATLAB's `[1xk]` conv2d over a `1xNx1` "image" is a 1-D convolution.

**Inference** (`detectLicksFromRaw`): slide the 3 s bout window with a 0.5 s step; on positive
windows, run netPoint centered on every sample; merge lick points within 20 ms; cluster center
is the lick time.

`meta` in `lickNets.mat`: fs=100, winSec=3, winSamples=300, centerSec=1, pointWin=21.

## Architecture

New in-repo package (committed, present on clone), selected by the `algorithm='ml'` flag — not a
separately installed opt-in package.

```
ml_detection/
  __init__.py
  nets.py         # LickBoutNet, LickPointNet — exact MATLAB topology in PyTorch
  weights_io.py   # read lickNets.mat (h5py) -> load conv/BN/FC + zscore scalars
  preprocess.py   # resample -> 100 Hz, per-window max-offset (shared train + infer)
  dataset.py      # h5 cap_data/time_data -> segments + labels; torch Dataset
  bootstrap.py    # seed labels via existing basic_algorithm threshold detector
  train.py        # refit normalization, fine-tune all layers, save checkpoints
  infer.py        # vectorized cascade -> lick_times; detect_licks() entry point
  labeler/app.py  # Panel curation app (+ labeler/logic.py pure helpers)
  checkpoints/    # ported + fine-tuned weights (.pt) + norm constants + meta
```

Each module has one clear responsibility and a narrow interface:

- `nets.py` — pure model definitions, no I/O.
- `weights_io.py` — `.mat` → state_dict; depends on `nets.py` for shapes.
- `preprocess.py` — deterministic signal transforms, no torch; shared so train and infer see
  identical inputs.
- `dataset.py` / `bootstrap.py` — build/curate labeled segments.
- `train.py` — fine-tuning driver.
- `infer.py` — the public `detect_licks()`; the only module `data_analysis.py` imports.
- `labeler/` — standalone Panel app (bokeh clickable trace), reads/writes curated HDF5. Pure
  edit logic lives in `labeler/logic.py` (unit-tested); `app.py` is the `panel serve` entrypoint.
  (Originally scoped as Solara, but a clickable trace with Python callbacks needs a Bokeh server
  backend; Panel — already a project dependency — provides that plus a filesystem file browser.)

### Integration point

In `data_analysis.py::filter_data` (currently dispatches `basic_threshold` / `hilbert`), add:

```python
elif algorithm == 'ml':
    missing_data = ml_algorithm(data_by_animal, filtered_h5f, logfile)
```

`ml_algorithm` mirrors `basic_algorithm`'s I/O contract: it writes the same per-animal datasets
(`lick_times`, `lick_indices`, and whatever else `basic_algorithm` emits) into `filtered_h5f`,
so downstream analysis and plotting need zero changes. Default remains `basic_threshold`.

## Component detail

### nets.py

`LickBoutNet`: `Conv1d(1,16,15,padding='same') -> BatchNorm1d -> ReLU -> MaxPool1d(4,4) ->
Conv1d(16,32,15,padding='same') -> BatchNorm1d -> ReLU -> Flatten -> Linear(_,32) -> ReLU ->
Linear(32,2)`.

`LickPointNet`: `Conv1d(1,16,5,padding='same') -> BatchNorm1d -> ReLU ->
Conv1d(16,32,5,padding='same') -> BatchNorm1d -> ReLU -> Flatten -> Linear(_,32) -> ReLU ->
Linear(32,2)`.

zscore normalization is the first op in `forward`: `(x - mean) / std`, with `mean`/`std`
registered as buffers so they save/load with the model and are refit during transfer learning.
softmax is applied outside for probabilities (CrossEntropyLoss consumes logits in training).

### weights_io.py — porting `lickNets.mat`

`.mat` v7.3 is HDF5; read with h5py (already a dependency). Mapping:

| MATLAB field | shape | PyTorch target |
|---|---|---|
| conv `Weights` | `[1, k, inC, outC]` | Conv1d weight `[outC, inC, k]` (permute; both cross-correlate, no kernel flip) |
| conv `Bias` | `[outC]` | Conv1d bias |
| BN `TrainedMean`, `TrainedVariance`, `Scale`, `Offset`, `Epsilon` | per-channel | BatchNorm1d `running_mean`, `running_var`, `weight`, `bias`, `eps` |
| FC `Weights` | `[out, in]` | Linear weight (see flatten-order fix) |
| FC `Bias` | `[out]` | Linear bias |
| input layer `Mean` / `Std` | scalar | zscore buffers |

**Critical flatten-order fix:** MATLAB flattens the conv output column-major as `[1, W, C]`;
PyTorch `Flatten` is row-major `[C, W]`. The first `Linear`'s input axis must be reindexed from
MATLAB `(W, C)` ordering to PyTorch `(C, W)` ordering, or the port silently produces garbage.
Implement as a permutation of the FC weight columns.

### preprocess.py

- Resample irregular `(time, cap)` to uniform 100 Hz via linear interpolation with extrapolation
  (`np.interp` / `scipy`), matching MATLAB `resampleCapacitance`.
- Offset `y - max(y)` so `max = 0`.

**Guiding principle: faithful-first.** The initial implementation reproduces the MATLAB behavior
*exactly as written*, including its quirks, so the parity gate can pass. Every offset convention
below matches MATLAB verbatim:

- Bout net input: per-**bout-window** offset (`y(win) - max(y(win))`).
- Point net input **at inference**: **global** offset (`y - max(y)` over the whole recording).
- Point net windows **at training**: per-**segment** offset (each training segment offset by its
  own max, as `buildInitialTrainingSet` does).

This means the MATLAB point net is trained under one offset convention and inferred under another
(a latent train/inference mismatch). We deliberately preserve it for the faithful port, and log
it as a deferred improvement to test (see Potential Improvements). Offset conventions live in
`preprocess.py` behind named functions so the improvement experiment is a one-line swap.

### bootstrap.py + dataset.py

1. Read **new-CDT** ACG-26-3 recordings, per sensor: `cap_data` (int64), `time_data` (float64).
   **CDT cutoff: 2026-07-22.** The MPR121 charge/discharge-time change took effect for data
   recorded **on 2026-07-22 and onward**, so only those files are in the new magnitude scale.
   Concretely, `results_combined_ACG-26-3_2026-07-22*.h5` are new-scale (training/fine-tune data);
   the earlier `2026-07-09` and `2026-07-21` files are **old-scale** and must NOT be mixed into
   the new-CDT training set. Match new-scale files explicitly by date, not a broad `2026-07*` glob.
2. Resample + offset via `preprocess.py`.
3. Seed lick marks by running the existing `basic_algorithm` threshold detector on each recording
   (far better starting point than MATLAB's findpeaks).
4. Sample 3 s windows (300 samples), central 1 s labeling region, using the same three categories
   as `buildInitialTrainingSet` (0 / 1-3 / >=4 licks in center) for balance.
5. Persist a training struct to **HDF5** (our own schema): `samples`, `t`, `lickIdx`,
   `labelsBout`, `fs`, `winSec`, `centerSec`, plus provenance (source recording, sensor, cycle).

### labeler/app.py — Panel curation tool

Port `lickLabelerGUI` behavior to Panel (bokeh clickable trace; Panel already in the env):

- Show one 3 s segment with the capacitance trace and red lick markers.
- Click on plot: add a lick at nearest sample, or select the nearest existing lick.
- Arrow keys / buttons: nudge selected lick +/-1 sample.
- Delete/remove selected lick.
- Prev/Next navigation across segments; list of lick times for the current segment.
- On every edit, recompute `labelsBout` = (>=1 lick in central 1 s), exactly as MATLAB.
- Save writes the curated segments back to HDF5.

### train.py — transfer learning

1. Load ported weights into both networks.
2. **Refit zscore:** recompute a single scalar mean/std over the new curated segments; overwrite
   the input-norm buffers. This is the primary fix for the CDT magnitude change.
3. **Split by recording/session** (hold out whole sessions for validation) to avoid leakage
   between adjacent overlapping windows.
4. Fine-tune **all** layers at a low learning rate (e.g. Adam 1e-4) with early stopping on the
   held-out split. Bout net trains on 3 s segments; point net trains on 21-sample windows over
   the central 1 s of positive segments (port of `preparePointSegments`).
5. Optional dataset transforms ported from MATLAB: `balanceTrainingByLickLocation` (central-lick
   vs no-central-lick, variance-spread negatives) and `makeThreeSecondTraining`-style
   augmentation.
6. Save fine-tuned `.pt` (state_dict incl. norm buffers) + meta (fs, winSec, pointWin, training
   provenance) to `checkpoints/`.

### infer.py — vectorized cascade

`detect_licks(cap_data, time_data, net_bout, net_point) -> lick_times`:

1. Resample -> 100 Hz, offset.
2. **Bout gate:** slide 3 s window, step 0.5 s (as MATLAB), but batch all windows through
   `LickBoutNet` in a single forward pass -> per-window lick/no-lick.
3. **Point pass (vectorized):** instead of MATLAB's per-sample re-classify loop, gather all
   21-sample windows centered on every sample inside positive bout spans as one batch (or run
   `LickPointNet` stride-1 over the positive span), single forward pass -> per-sample lick mask.
   This is the one intentional deviation from MATLAB-as-written, but it is **output-identical**
   (same inputs, same labels) — a pure speed optimization, not a behavior change — and validation
   gate #2 confirms it reproduces the loop's result. Overlapping positive bout windows are reduced
   to their **union** before the batch: because the point net input uses the global offset, a
   sample's label is independent of which bout window reached it, so the union is lossless and
   matches MATLAB's OR semantics (`lickMaskGlobal` is set and never unset).
4. Merge mask points within 20 ms; cluster center = lick time (port of MATLAB merge logic).
5. Map times back to the original time base; return.

`ml_algorithm` wraps `detect_licks` per animal and writes the same HDF5 datasets as
`basic_algorithm`.

## Validation (gates, in order)

1. **Weight-port parity.** Generate reference `(input, softmax-output)` pairs from the real
   MATLAB networks using headless MATLAB
   (`/Applications/MATLAB_R2025a.app/bin/matlab -batch "..."`; MATLAB R2025a is installed).
   Assert the PyTorch port matches to ~1e-4. **Must pass before any fine-tuning** — fine-tuning
   from mis-loaded weights is worthless.
2. **Pre-fine-tune sanity.** The ported (un-fine-tuned) net on an *old-CDT* recording reproduces
   the old MATLAB detection behavior. Use a **pre-2026-07-22** file (e.g.
   `results_combined_ACG-26-3_2026-07-21.h5` or `_2026-07-09_...h5`) — these are still in the old
   magnitude scale the saved weights were trained on, so they are the correct oracle for this
   gate.
3. **Post-fine-tune metrics.** Precision / recall / F1 on held-out sessions against curated
   labels; compare to the threshold detector on the same sessions.
4. **Timing spot-check.** Overlay ML lick times on the trace (and sync video where available) for
   a few bouts; confirm no systematic offset.

## Testing

- Unit tests, mirroring the existing `tests/` layout:
  - `preprocess`: resample invariants (length, endpoint handling), offset correctness.
  - `weights_io`: shape mapping, flatten-order permutation, parity against MATLAB reference
    vectors.
  - `infer`: bout-window slicing, point-window gathering equals the naive loop on a small
    fixture, 20 ms merge logic.
- Small fixture HDF5 recording committed for fast tests.

## Dependencies

- **New:** `torch` (CPU wheel) added to `requirements.txt` and `environment.yml`.
- Already present and reused: `h5py` (read `.mat` v7.3 and project h5), `numpy`, `scipy`
  (resample / threshold detector), `matplotlib`, `solara` / `panel` / `ipywidgets` (labeler).

## Potential improvements (deferred)

The first implementation is a faithful MATLAB port. While planning/building, log candidate
improvements here rather than acting on them, so the parity gate stays meaningful. Each is a
post-parity experiment, measured on held-out-session F1.

1. **Fix the point-net train/inference offset mismatch (prioritized to test).** MATLAB trains the
   point net on per-segment-offset windows but infers under global offset. Experiment: use the
   **per-segment offset for BOTH training and inference** and compare F1 to the faithful port.
   Requires the offset functions in `preprocess.py` to be swappable (already specified).
2. **Bout-gate overlap resolution.** MATLAB resolves overlapping bout windows with OR (any
   positive window makes the span positive). Alternative: `gate_mode='vote'` requiring a majority
   of covering bout windows to agree — more conservative, possibly better generalization. Add as
   a flag after parity.
3. **Reuse of prior ML artifacts.** The repo already contains `checkpoints/best.pt` and training
   data from earlier, un-integrated ML experiments (per project CLAUDE.md). During planning,
   inspect these — the checkpoint architecture, any labeled data, and how `best.pt` was produced —
   before generating fresh labels; they may seed or replace parts of this pipeline.
4. **Combine ML with the threshold detector.** Longer term, ML could become the default or be
   fused with `basic_algorithm` (e.g. ML gates, threshold refines timing, or ensemble). Out of
   scope for the faithful port.

## Open questions / risks

- **Flatten-order fix** is the highest-risk detail; the parity gate (validation #1) is designed
  specifically to catch it.
- Amount of new labeled data needed for stable fine-tuning is unknown; start with ACG-26-3
  2026-07 sessions and expand if held-out F1 is unsatisfactory.
- BatchNorm behavior during fine-tuning on a small dataset: consider freezing BN running stats or
  using a low momentum; decide during implementation based on validation.

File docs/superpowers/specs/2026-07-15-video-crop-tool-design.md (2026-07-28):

# Standalone Video Crop Tool — Design

**Date:** 2026-07-15
**Status:** SUPERSEDED (2026-07-28) — see note below. Historical record.

> ## Superseded: crop is now a display-time slice
>
> This spec's crop-first design (crop_video writes a re-encoded
> `<video>_cropped.mp4`; make_sync_video times that file) shipped a sync bug and
> has been replaced.
>
> **Why it failed:** re-encoding to apply the crop REGENERATES the video's PTS
> onto a fresh CFR grid — wrong phase (off the original frame grid by a
> non-integer number of frames) and a rate rounded from the true ~120.0048 fps to
> a flat 120.0. `probe_frame_session_times` recovers each frame's original
> container ordinal via `round(pts_time * rate)` to index `container_pts_ns`; on a
> re-encoded file both inputs are wrong, so a crop-first render drifted ~1.6 s late
> on a late clip. The uncropped path never re-encodes (`subclip_copy` is a stream
> copy), so it stayed aligned. `-fps_mode passthrough` fixes only the rate part
> (~0.27 s), not the phase — a dead end.
>
> **New design:** the crop is a pure spatial numpy slice applied at RENDER time.
> - `crop_video.py` is now a box picker only: it writes `<base>_crop.json`
>   (`{x, y, size}`) via `write_crop_params`. No ffmpeg encode, no cropped video.
> - `make_sync_video.py` always times the ORIGINAL recording (`resolve_paths` no
>   longer prefers a cropped file). `load_crop` reads the sidecar (`--no-crop` to
>   skip, `--crop-params` to override); `render_clip(..., crop=box)` hands it to
>   `TrimmedFrameSource`, which slices each decoded frame with `crop_frame` before
>   display. The timing path is byte-for-byte the working uncropped path.
> - New primitives in `video/trimcrop.py`: `CropBox`, `crop_params_path`,
>   `write_crop_params`, `read_crop_params`, `crop_frame`.
> - `trim_and_crop` / `cropped_path_for` / `resolve_paths(prefer_cropped=)` remain
>   but are unused by production. Stale `*_cropped.mp4` files are ignored — delete.
>
> Everything below is the original 2026-07-15 crop-first design, kept for history.

---

**Date:** 2026-07-15
**Status:** Approved (design), pending implementation plan

## Goal

A standalone tool that trims a Pi video recording to its capacitance-recording
window and crops it to a square region the user positions by hand. Produces a
`<video>_cropped.mp4` that `make_sync_video.py` then consumes directly.

Today `make_sync_video.py` trims and center-crops on every render. The crop
region is hard-coded to the frame center, which is rarely where the sipper is,
and the (expensive, re-encoding) trim+crop is repeated for every clip rendered
from the same recording. This design moves that work into a one-time
interactive step.

Reference recording:
`Lickometry Data/ACG-26-3/raw_data_2026-07-13_11-59-47.{mp4,h5,txt}`
(1280x720, nominal 240 fps).

## Scope

- New root script `crop_video.py`: CLI + matplotlib GUI.
- New module `video/trimcrop.py`: shared pure functions and ffmpeg wrappers,
  extracted from `make_sync_video.py`.
- `make_sync_video.py` stops trimming and cropping; it consumes the cropped
  file and only cheaply subclips (stream copy) to its `--start`/`--end` window.

Out of scope: batch/headless cropping, persisting crop positions across
recordings, resizable crop boxes in the GUI, cropping non-square regions.

## Established facts

- Raw h5 layout: `board_FT232H{0..3}/sensor_{n}/`. Exactly one sensor carries
  `video_filename`, `video_frame_index`, `video_pts` — found by
  `find_video_sensor()`.
- Session window comes from that sensor's `start_time`/`stop_time`; numbered
  variants (`start_time1`, …) exist for multi-cycle recordings and the
  highest-numbered pair wins (`_resolve_start_stop()`, mirrors `filter_data`).
- The PTS sidecar `<video>.txt` holds one nanosecond timestamp per frame of the
  **original** video.
- `video_base = (pts[video_frame_index] - pts[0]) / 1e9` — seconds from the
  first frame to the bookmarked (sipper-insertion) frame.
- The bookmark round-trip lagged `start_time`, so the raw anchor runs early by
  `bookmark_latency(host_before, host_after, start_time)`; the corrected anchor
  is `video_base_eff = video_base - latency`. Older recordings lack the host
  bracket and get latency 0.
- ffmpeg's input `-ss` does not land frame-accurately on this footage. Every
  trim uses `-copyts` so output frames keep original PTS, and frames are timed
  by their real PTS (read back with ffprobe) — never by where the seek landed.

## Architecture

### `video/trimcrop.py` (new)

Pure functions and ffmpeg wrappers, no GUI, no argparse. Moved verbatim from
`make_sync_video.py` unless noted:

- `find_video_sensor(raw_h5)`
- `_resolve_start_stop(group)`
- `read_session_window(h5_path)` — returns `(start_time, stop_time)`.
  `read_session_duration()` in `make_sync_video.py` becomes a thin caller.
- `compute_video_base(pts_ns, frame_index)`
- `bookmark_latency(host_before, host_after, start_time)`
- `frame_session_times(pts_ns, video_base)`
- `compute_trim_frames(pts_ns, video_base, start, end)`
- `probe_frame_session_times(path, video_base)`
- `read_video_anchor(h5_path)` — new: reads `video_frame_index`, the host
  bracket, and start/stop in one open; returns everything needed to compute
  `video_base_eff`. Both scripts need this, neither should re-open the h5.

Changed signature:

- `trim_and_crop(video_path, start_sec, end_sec, out_path, crop_x, crop_y,
  size, seek_margin=5.0)` — **crop origin is now explicit**, replacing the
  centered `(iw-w)/2` expression. Filter becomes
  `crop={size}:{size}:{crop_x}:{crop_y}`. Re-encodes (libx264, veryfast,
  crf 18, yuv420p) because a filter is applied.

New:

- `probe_start_pts(path)` — new: the input's first presentation timestamp, via
  `ffprobe -show_entries format=start_time`.
- `subclip_copy(video_path, start_sec, end_sec, out_path, seek_margin=5.0)` —
  `ffmpeg -ss <coarse> -copyts -i <in> -to <end> -an -c copy <out>`. No filter,
  no re-encode, near-instant. Stream copy cuts at the keyframe at or before
  the seek target, so the clip may carry leading frames earlier than
  `start_sec`; that is harmless because consumers time frames by PTS and skip
  past them.

  **Input `-ss` is file-relative; `-to` with `-copyts` is absolute.** Verified
  experimentally on the reference recording: a cropped file whose PTS start at
  30 s yields zero frames for `-ss 35`, and seeks correctly for `-ss 5`, while
  `-to 40` cuts at absolute 40 s either way. So the seek must be

      coarse = max(0.0, start_sec - probe_start_pts(video_path) - seek_margin)

  `start_sec` is always an original-video-timeline second. The original video's
  `start_time` is 0.0, so this reduces to today's behavior there; the cropped
  file's `start_time` is the session start (~32 s), where the subtraction is
  what makes the seek land. `trim_and_crop` reads the original video only and
  keeps the plain `start_sec - seek_margin` seek.
- `clamp_origin(x, y, frame_w, frame_h, size)` — clamps a proposed crop origin
  so the box stays inside the frame, and rounds each coordinate down to an even
  number (yuv420p chroma subsampling requires even offsets). Raises `ValueError`
  if `size` exceeds either frame dimension. Pure; unit-tested.

### `crop_video.py` (new root script)

```
python crop_video.py --h5 <raw.h5> [--video X] [--pts-txt Y] [--size 360]
                     [--out Z] [--force]
```

Flow:

1. `shutil.which("ffmpeg")` check; error out early if missing.
2. Resolve video and PTS sidecar (see "Path resolution" below). `crop_video.py`
   always operates on the **original** video, never on an existing
   `_cropped.mp4`; if resolution lands on one, error out.
3. `read_video_anchor(h5)` → `video_base_eff = compute_video_base(pts,
   frame_index) - bookmark_latency(...)`.
4. `session_duration = stop_time - start_time`;
   `compute_trim_frames(pts, video_base_eff, 0.0, session_duration)` →
   `(start_frame, stop_frame)` → video-seconds
   `start_sec = (pts[start_frame]-pts[0])/1e9`, `end_sec` likewise `+ 0.3`
   (same tail margin `render_clip` uses today).
5. Preview frame: `imageio.get_reader(video).get_data(mid_frame)` where
   `mid_frame = (start_frame + stop_frame) // 2` — the midpoint of the **trim
   window**, not of the file, so the mouse is present and the sipper is in.
6. Launch GUI (below). Window closed without pressing Crop → exit 0, no output
   written, print `cancelled`.
7. On Crop: close the figure, then
   `trim_and_crop(video, start_sec, end_sec, out, x, y, size)`. Print the
   window, the crop origin, and the output path.

Default `--out` is `<video-base>_cropped.mp4` (matches the file already on disk
in `Lickometry Data/ACG-26-3/`). Refuse to overwrite an existing output unless
`--force`. The original video is never modified.

### GUI

Matplotlib only — no new dependencies, and matplotlib is already used
throughout the repo.

- `ax.imshow(frame)`; `Rectangle((x0, y0), size, size, fill=False, lw=2,
  edgecolor="lime")` starting centered.
- `button_press_event`: if the click is inside the rect, record the grab offset.
- `motion_notify_event`: while grabbed, move the rect to
  `clamp_origin(event.xdata - dx, event.ydata - dy, W, H, size)`.
- `button_release_event`: release the grab.
- `Button` widget labelled "Crop" in the lower right; sets a result flag and
  closes the figure.
- Axes title shows the live crop origin, e.g. `crop 360x360 @ (452, 180)`.

Drag only — the box is locked to `--size` (default 360). No resize handles:
a fixed size keeps output dimensions consistent across recordings and removes a
whole class of accidental-resize mistakes.

### `make_sync_video.py` (changed)

- Deletes its own copies of the functions now in `video/trimcrop.py` and
  imports them instead.
- `render_clip` calls `subclip_copy` where it called `trim_and_crop`. It no
  longer crops — whatever crop the input file has is what the panel shows.
- Drops `--crop-w` / `--crop-h`.
- `--intermediate` keeps its meaning (the subclip file, still kept).
- Everything downstream is unchanged: `probe_frame_session_times` reads the
  subclip's preserved PTS, `TrimmedFrameSource` matches frames by session time.

## Path resolution

Shared helper `resolve_paths(h5_path, video, pts_txt, prefer_cropped)`:

1. Base video name always comes from the h5's `video_filename`, joined to the
   h5's directory. Call this `<base>.mp4`.
2. **PTS sidecar is always `<base>.txt`** — derived from the original video
   name, never from the resolved video path. `--pts-txt` overrides.
3. Video path:
   - `--video X` → X verbatim.
   - `prefer_cropped=True` (make_sync_video) → `<base>_cropped.mp4` if it
     exists, else `<base>.mp4` plus a stderr note:
     `note: using uncropped video <path> (no _cropped.mp4; run crop_video.py first)`.
   - `prefer_cropped=False` (crop_video) → `<base>.mp4`.

The sidecar rule matters: today's `resolve_paths` derives it as
`splitext(video)[0] + ".txt"`, which would look for a nonexistent
`<base>_cropped.txt` the moment the cropped file is preferred. The cropped
video has no sidecar of its own and needs none — it carries original PTS via
`-copyts`, and `probe_frame_session_times` reads them back from the file.

The uncropped fallback renders correctly; the video panel is just the full
1280x720 frame instead of a 360x360 crop.

## Error handling

Matches the existing style: `video/trimcrop.py` raises `ValueError` /
`RuntimeError` with a specific message; `main()` catches
`(ValueError, FileNotFoundError, KeyError, OSError, RuntimeError)`, prints
`error: {e}` to stderr, returns 1.

Specific cases:

- ffmpeg not on PATH → early check in `main()`.
- No sensor with `video_filename` → `find_video_sensor` raises.
- No frames in the session window → `compute_trim_frames` raises.
- Output exists and no `--force` → `ValueError`.
- `--video` points at a `_cropped.mp4` → `ValueError` (double-cropping).
- ffmpeg non-zero exit → `RuntimeError` with the last 800 chars of stderr.

## Testing

New `tests/test_trimcrop.py`, pure functions only:

- `clamp_origin`: inside frame unchanged (modulo even rounding); each edge
  clamps; oversized `size` vs frame errors; odd inputs round down to even.
- `compute_trim_frames`: window edges inclusive; empty window raises.
- `_resolve_start_stop`: picks the highest-numbered pair; unnumbered pair; no
  pair falls back to `time_data` ends.
- `resolve_paths`: sidecar stays `<base>.txt` when the cropped video is
  preferred; `--video` override; `prefer_cropped` picks cropped when present
  and falls back when absent.
- `trim_and_crop` / `subclip_copy`: assert the constructed ffmpeg argv
  (crop filter string, `-copyts`, `-c copy` vs `-c:v libx264`) with
  `subprocess.run` patched. ffmpeg is not executed in tests.

`tests/test_make_sync_video.py` is updated for the moved functions and the
dropped `--crop-w`/`--crop-h` flags.

The GUI is deliberately thin (event handlers delegating to `clamp_origin`) and
is not unit-tested; it is verified by running the tool on the reference
recording.

## Verification

Run against `Lickometry Data/ACG-26-3/raw_data_2026-07-13_11-59-47.h5`:

1. `python crop_video.py --h5 <ref>.h5` → drag box over the sipper → Crop.
   Confirm `<ref>_cropped.mp4` is 360x360 and its duration matches
   `stop_time - start_time`.
2. `python make_sync_video.py --h5 <ref>.h5 --layout <layout> --start 60
   --end 70 --out /tmp/clip.mp4` → confirm it picks the cropped file, the
   panel shows the chosen region, and licks still line up with the trace.
3. Move `<ref>_cropped.mp4` aside; rerun step 2 → confirm the fallback note
   prints and the clip renders with the full uncropped frame.

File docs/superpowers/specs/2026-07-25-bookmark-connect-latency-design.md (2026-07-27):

# Bookmark connect-latency fix: cache the resolved IPv4 per session

**Date:** 2026-07-25
**Status:** Approved (design)
**Scope:** `hardware/pi_camera.py` only (plus tests)

## Problem

Video↔trace sync on a full run (`raw_data_2026-07-24_12-02-14`, ACG-26-3) showed the
video running ~25 frames (~0.2s) ahead of the capacitance trace mid/late session,
after the earlier CFR-drift fix already removed the gross ~950-frame drift.

Root cause, confirmed by direct measurement from the recording desktop:

```
getaddrinfo('picamera0.local', 8770) -> [ fe80::… (IPv6 link-local, DEAD), 192.168.50.2 (IPv4, good) ]
connect IPv6 : FAILS after ~2024 ms   (tried first, every call)
connect IPv4 : OK in ~24 ms
hostname PING (what the recorder does): 2060–4749 ms, spread 2689 ms
direct-IP PING                         :    1–23 ms, spread 22 ms
```

`PiCameraClient._request` calls `socket.create_connection(('picamera0.local', 8770),
timeout=5.0)` on **every** request. `getaddrinfo` returns the dead IPv6 link-local
address first, so each call wastes ~2–4.7s connecting to it before falling back to
the working IPv4 in ~24ms. The **call-to-call variance** in that stall (2060 vs
4749 ms) differs between the Start and Stop bookmarks and skews the two-bookmark
`slope`, which is what shifts the video against the trace over the session.

Transport is **wired only** (wifi is disabled on the Pi; the "roaming wlan0 guest
SSID" comments in this file are stale). The Pi's reply itself is <1ms.

### What this fix does and does not claim

- **Confirmed wins:** bookmark round-trip drops from ~2–5s to ~20ms, removing the
  2–5s uncertainty window and the near-`timeout=5.0` stalls that risk bookmark
  retries / lost anchors (a prior run lost its anchor this way). `host_after`
  becomes a tight proxy for the Pi's bookmark-exec instant.
- **Not asserted here:** that this alone zeroes the 25-frame residual. Because the
  Pi reply is <1ms even now, a smaller secondary component (reply-latency variance
  under encoding load) may remain. That is validated only by re-recording after
  this lands, and is out of scope for this change.

## Design

All changes are inside `hardware/pi_camera.py`.

### Address cache on the client instance

- New instance field `self._addr` (default `None`): a cached `(family, socktype,
  proto, sockaddr)` tuple of the address that last connected successfully.
- The session-lived singleton `session_controls.camera_client` is created once at
  session start and reused for `start_session`, both bookmarks, `stop_session`, and
  `get_file`. Caching on the instance therefore resolves once per session; every
  later call takes the fast direct-IP path.

### `_connect()` helper (replaces the bare `create_connection` in `_request`)

```
CONNECT_TIMEOUT_S = 0.1   # per-address; IPv4 measured ~1–24 ms, 4x+ margin

def _connect(self):
    # 1. Fast path: reuse the cached address.
    if self._addr is not None:
        try:
            return self._connect_addr(self._addr)
        except OSError:
            self._addr = None      # stale (e.g. DHCP change) -> fall through, re-resolve

    # 2. Resolve, IPv4 before IPv6, connect the first that answers; cache it.
    infos = socket.getaddrinfo(self.host, self.port, proto=socket.IPPROTO_TCP)
    infos.sort(key=lambda i: i[0] != socket.AF_INET)   # AF_INET first
    last_exc = None
    for info in infos:
        try:
            sock = self._connect_addr(info)
            self._addr = info      # cache the working address
            return sock
        except OSError as exc:
            last_exc = exc
    raise last_exc if last_exc else OSError("no addresses for %s" % self.host)
```

- `_connect_addr(info)` opens a socket for `info`'s family, sets
  `CONNECT_TIMEOUT_S`, connects to its sockaddr, then restores `self.timeout` for
  the send/recv phase, and returns the connected socket.
- `_request` wraps `self._connect()` in the existing `try/except Exception ->
  make_error(...)` so callers still get an error dict, never an exception. The
  per-request full timeout (`self.timeout`) continues to govern send/recv; only the
  connect phase uses the short per-address timeout.

### Comment cleanup

Replace the stale "roaming wlan0 on a guest SSID" wording in `_request`'s except
block with an accurate note: transport is the wired link; name resolution can list
a dead IPv6 link-local first, which is why the connected address is cached.

## Error handling

- Connect failure → same `make_error(f"{exc} [{host}:{port}]")` dict as today.
- A cached address that stops connecting (IP reassigned mid-session) self-heals:
  the failed fast-path connect clears `self._addr` and the same `_connect` call
  re-resolves once.
- If both IPv4 and IPv6 fail (Pi down), `_connect` raises, `_request` returns the
  error dict, and `_bookmark_with_retry` retries exactly as it does now.

## Testing

Mirror `tests/test_bookmark_retry.py` (monkeypatch) and
`tests/test_hardware_camera_persistence.py` (live loopback socket).

1. **IPv4-first, skip dead IPv6:** monkeypatch `getaddrinfo` to return
   `[IPv6-dead, IPv4-good]`; a fake connector records attempt order. Assert the
   IPv4 address is tried first (the sort puts `AF_INET` ahead of the dead IPv6
   link-local) and the client connects to it without ever attempting the IPv6 one.
   A separate case where the IPv4 connect is made to time out asserts the fallback
   then abandons it within the short per-address timeout and moves on.
2. **Resolve once, then cache:** two successive `_request` calls; assert
   `getaddrinfo` is called exactly once and the second call connects straight to the
   cached address.
3. **Stale-cache re-resolve:** prime the cache, then make the cached address fail;
   assert exactly one re-resolution and a successful connect to the new address.
4. **Error path unchanged:** all addresses fail → `_request` returns a
   `make_error` dict (no exception), so `_bookmark_with_retry` still retries.
5. **Live loopback:** a real `socketserver` on `127.0.0.1` answers `PING`; assert a
   normal `_request` round-trips and populates `self._addr`.

## Out of scope

- Reply-latency variance under encoding load (possible secondary residual).
- Any change to the desktop callers, `_bookmark_with_retry`, the anchor math in
  `video/trimcrop.py`, or the h5 schema.
- Switching the configured host away from `picamera0.local` (kept by decision).
- Pi-side IPv6/AAAA disabling (an ops option, not this code change).

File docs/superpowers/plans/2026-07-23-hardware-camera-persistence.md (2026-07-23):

# Hardware & Camera State Persistence Implementation Plan

> **For agentic workers:** REQUIRED SUB-SKILL: Use superpowers:subagent-driven-development (recommended) or superpowers:executing-plans to implement this plan task-by-task. Steps use checkbox (`- [ ]`) syntax for tracking.

**Goal:** Make initialized hardware, the concurrent-video controls, and Start/Stop bookmark delivery to the Pi survive a browser refresh by putting their reactive state on the existing session-persistence mechanism.

**Architecture:** Reuse PR #5's pattern — an authoritative plain-global `session` dict mirrored into per-context `solara.reactive`s via `set_session()`, rehydrated on `Page` mount by `rehydrate_reactives_from_session()`. This plan only adds keys to `session`/`_REACTIVE_FOR` and reroutes existing bare `.set(...)` writes through `set_session(...)`. The rehydrate path and `recording_gui.py` are unchanged; the bookmark fix falls out for free because the bookmark gates read `camera_enabled`/`camera_sensor_id`, which now survive refresh.

**Tech Stack:** Python 3.13, Solara (reactive web GUI), pytest.

## Global Constraints

- Persistence mechanism is fixed: authoritative writes go through
  `state.set_session(key, value)`; never add a new persistence path.
- Only these keys are added to persistence — hardware: `boards_connected`,
  `i2c_controllers`; camera: `camera_enabled`, `camera_sensor_id`,
  `camera_host`, `camera_port`, `camera_video_filename`, `camera_disk_warning`,
  `camera_stall_warning`, `camera_status`.
- Do NOT persist transient UI reactives: `snapshot_image`, `snapshot_error`,
  `snapshot_pending`, `show_snapshot_dialog`, `show_test_dialog`,
  `test_plot_data`, `log_messages`.
- Default values in `session` must exactly match each reactive's current default
  in `utils/state.py`.
- Read sites (`state.<x>.value`) stay unchanged — only writes are rerouted.
- Run tests with `pytest` from the repo root (`/Users/christopher/TimmeLab/CLiQR`).

---

### Task 1: Add hardware + camera keys to the persistence mechanism

**Files:**
- Modify: `utils/state.py` (`session` dict ~lines 97-102, `_REACTIVE_FOR` map ~lines 104-109)
- Test: `tests/test_hardware_camera_persistence.py` (create)

**Interfaces:**
- Consumes: existing `state.set_session(key, value)`,
  `state.rehydrate_reactives_from_session()`, `state.session`,
  `state._REACTIVE_FOR`, and the reactives `boards_connected`,
  `i2c_controllers`, `camera_enabled`, `camera_sensor_id`, `camera_host`,
  `camera_port`, `camera_video_filename`, `camera_disk_warning`,
  `camera_stall_warning`, `camera_status` (all already defined in `state.py`).
- Produces: those ten keys become valid arguments to `set_session` and are
  restored by `rehydrate_reactives_from_session`.

- [ ] **Step 1: Write the failing test**

Create `tests/test_hardware_camera_persistence.py`:

```python
"""Hardware and camera reactives must ride the same session-persistence
mechanism as the recording lifecycle, so a browser refresh (a fresh Solara
kernel context) restores initialized hardware, the video controls, and the
bookmark-gate values instead of showing defaults."""
from utils import state

# The full set of keys this feature adds to the persistence mechanism.
NEW_PERSISTED_KEYS = [
    "boards_connected",
    "i2c_controllers",
    "camera_enabled",
    "camera_sensor_id",
    "camera_host",
    "camera_port",
    "camera_video_filename",
    "camera_disk_warning",
    "camera_stall_warning",
    "camera_status",
]

def test_new_keys_are_registered_for_persistence():
    # Every new key must exist in BOTH the authoritative global (session) and
    # the reactive-mirror map, or rehydrate would skip it on refresh.
    for key in NEW_PERSISTED_KEYS:
        assert key in state.session, f"{key} missing from session dict"
        assert key in state._REACTIVE_FOR, f"{key} missing from _REACTIVE_FOR"

def test_session_defaults_match_reactive_defaults():
    # The durable twin must start equal to the reactive's own default, so a
    # first-ever mount rehydrates to a no-op rather than changing state.
    assert state.session["boards_connected"] == {}
    assert state.session["i2c_controllers"] == {}
    assert state.session["camera_enabled"] is False
    assert state.session["camera_sensor_id"] is None
    assert state.session["camera_host"] == "picamera0.local"
    assert state.session["camera_port"] == 8770
    assert state.session["camera_video_filename"] == ""
    assert state.session["camera_disk_warning"] == ""
    assert state.session["camera_stall_warning"] == ""
    assert state.session["camera_status"] == "unknown"

def test_hardware_survives_a_simulated_refresh():
    # Simulate an initialized run: two boards connected, live controller dict.
    fake_controllers = {"FT232H0": object(), "FT232H1": object()}
    state.set_session("boards_connected", {"FT232H0": 6, "FT232H1": 6})
    state.set_session("i2c_controllers", fake_controllers)

    # Simulate a NEW kernel context: reactives reset to defaults, global intact.
    state.boards_connected.set({})
    state.i2c_controllers.set({})

    state.rehydrate_reactives_from_session()

    # The Hardware card branches on boards_connected being truthy.
    assert state.boards_connected.value == {"FT232H0": 6, "FT232H1": 6}
    # Same live controller objects re-pointed, not copies.
    assert state.i2c_controllers.value is fake_controllers

    # Cleanup so other tests see defaults.
    state.set_session("boards_connected", {})
    state.set_session("i2c_controllers", {})

def test_camera_enable_and_bookmark_sensor_survive_a_refresh():
    # The bookmark gate is: camera_enabled AND sensor_id == camera_sensor_id.
    state.set_session("camera_enabled", True)
    state.set_session("camera_sensor_id", 5)

    # New context: reactives back at defaults.
    state.camera_enabled.set(False)
    state.camera_sensor_id.set(None)

    state.rehydrate_reactives_from_session()

    assert state.camera_enabled.value is True
    assert state.camera_sensor_id.value == 5
    # Gate for sensor 5 now evaluates true again -> Start/Stop send bookmarks.
    assert state.camera_enabled.value and 5 == state.camera_sensor_id.value

    # Cleanup.
    state.set_session("camera_enabled", False)
    state.set_session("camera_sensor_id", None)
```

- [ ] **Step 2: Run test to verify it fails**

Run: `pytest tests/test_hardware_camera_persistence.py -v`
Expected: FAIL — `test_new_keys_are_registered_for_persistence` asserts the
keys are missing from `state.session` / `state._REACTIVE_FOR`.

- [ ] **Step 3: Add the keys to `session` and `_REACTIVE_FOR`**

In `utils/state.py`, extend the `session` dict (currently ends at the
`sensor_states` entry) so it reads:

```python
session = {
    "recording_all": False,
    "filename": "",
    "comments": "",
    "sensor_states": {i: SensorState(sensor_id=i) for i in range(1, 25)},
    # Hardware — live handles stay open in the server process across a browser
    # refresh; these hold the same references so a fresh context can be
    # re-pointed at them without a USB re-scan.
    "boards_connected": {},
    "i2c_controllers": {},
    # Camera run-state + config (concurrent Pi video capture).
    "camera_enabled": False,
    "camera_sensor_id": None,
    "camera_host": "picamera0.local",
    "camera_port": 8770,
    "camera_video_filename": "",
    "camera_disk_warning": "",
    "camera_stall_warning": "",
    "camera_status": "unknown",
}
```

And extend `_REACTIVE_FOR` to:

```python
_REACTIVE_FOR = {
    "recording_all": recording_all,
    "filename": filename,
    "comments": comments,
    "sensor_states": sensor_states,
    # Hardware
    "boards_connected": boards_connected,
    "i2c_controllers": i2c_controllers,
    # Camera
    "camera_enabled": camera_enabled,
    "camera_sensor_id": camera_sensor_id,
    "camera_host": camera_host,
    "camera_port": camera_port,
    "camera_video_filename": camera_video_filename,
    "camera_disk_warning": camera_disk_warning,
    "camera_stall_warning": camera_stall_warning,
    "camera_status": camera_status,
}
```

- [ ] **Step 4: Run test to verify it passes**

Run: `pytest tests/test_hardware_camera_persistence.py -v`
Expected: PASS (all four tests).

- [ ] **Step 5: Run the full suite to confirm nothing regressed**

Run: `pytest -q`
Expected: PASS (existing session-persistence tests still green).

- [ ] **Step 6: Commit**

```bash
git add utils/state.py tests/test_hardware_camera_persistence.py
git commit -m "feat: persist hardware & camera reactives across refresh

Add boards_connected, i2c_controllers, and the camera run-state/config
reactives to the session dict and _REACTIVE_FOR so rehydrate restores
them on a fresh kernel context.

Co-Authored-By: Claude Opus 4.8 <noreply@anthropic.com>"
```

---

### Task 2: Route hardware writes through `set_session`

**Files:**
- Modify: `components/hardware_status.py` (`initialize_hardware` lines 26, 40, 44, 55; `disconnect_hardware` lines 116-117)
- Modify: `hardware/mock_hardware.py` (`mock_initialize` lines 247, 258)
- Test: `tests/test_hardware_camera_persistence.py` (append)

**Interfaces:**
- Consumes: `state.set_session` (Task 1), the `boards_connected` /
  `i2c_controllers` keys registered in Task 1.
- Produces: `initialize_hardware`, `disconnect_hardware`, and mock
  `mock_initialize` write hardware state through `set_session`, so a real or
  mock init survives refresh.

- [ ] **Step 1: Write the failing test**

Append to `tests/test_hardware_camera_persistence.py`:

```python
import inspect

def test_hardware_writes_go_through_set_session():
    # Guards against a future edit re-introducing a bare .set() that would
    # silently drop hardware state on refresh again. We inspect source because
    # exercising real FT232H init needs physical USB boards.
    from components import hardware_status

    for func in (hardware_status.initialize_hardware,
                 hardware_status.disconnect_hardware):
        src = inspect.getsource(func)
        assert "boards_connected.set(" not in src, (
            f"{func.__name__} still writes boards_connected with bare .set()")
        assert "i2c_controllers.set(" not in src, (
            f"{func.__name__} still writes i2c_controllers with bare .set()")

def test_mock_initialize_goes_through_set_session():
    from hardware import mock_hardware

    src = inspect.getsource(mock_hardware)
    # mock_initialize is defined inside a setup function; check the module text.
    assert "i2c_controllers.set(" not in src, (
        "mock_initialize still writes i2c_controllers with bare .set()")
    assert "boards_connected.set(" not in src, (
        "mock_initialize still writes boards_connected with bare .set()")
```

- [ ] **Step 2: Run test to verify it fails**

Run: `pytest tests/test_hardware_camera_persistence.py -k hardware_writes -v`
Expected: FAIL — bare `boards_connected.set(` / `i2c_controllers.set(` still
present.

- [ ] **Step 3: Reroute writes in `components/hardware_status.py`**

Replace each bare hardware write:

- Line 26: `state.boards_connected.set({})` →
  `state.set_session("boards_connected", {})`
- Line 40: `state.boards_connected.set({})` →
  `state.set_session("boards_connected", {})`
- Line 44: `state.i2c_controllers.set(controllers)` →
  `state.set_session("i2c_controllers", controllers)`
- Line 55: `state.boards_connected.set(board_info)` →
  `state.set_session("boards_connected", board_info)`
- Line 116 (inside `disconnect_hardware`): `state.boards_connected.set({})` →
  `state.set_session("boards_connected", {})`
- Line 117: `state.i2c_controllers.set({})` →
  `state.set_session("i2c_controllers", {})`

- [ ] **Step 4: Reroute writes in `hardware/mock_hardware.py`**

- Line 247: `state.i2c_controllers.set(controllers)` →
  `state.set_session("i2c_controllers", controllers)`
- Line 258: `state.boards_connected.set(board_info)` →
  `state.set_session("boards_connected", board_info)`

- [ ] **Step 5: Run test to verify it passes**

Run: `pytest tests/test_hardware_camera_persistence.py -k "hardware_writes or mock_initialize" -v`
Expected: PASS.

- [ ] **Step 6: Run the full suite**

Run: `pytest -q`
Expected: PASS.

- [ ] **Step 7: Commit**

```bash
git add components/hardware_status.py hardware/mock_hardware.py tests/test_hardware_camera_persistence.py
git commit -m "feat: route hardware writes through set_session

initialize_hardware, disconnect_hardware, and the mock initializer now
persist boards_connected/i2c_controllers so initialized hardware shows
after a browser refresh instead of the Initialize button.

Co-Authored-By: Claude Opus 4.8 <noreply@anthropic.com>"
```

---
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

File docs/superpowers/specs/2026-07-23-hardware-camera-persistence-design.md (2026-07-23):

# Hardware & Camera State Persistence Across Refresh

**Date:** 2026-07-23
**Status:** Approved design

## Problem

The 2026-07-22 session-state-persistence work (PR #5) made the recording
lifecycle and measurements survive a browser refresh / websocket reconnect. But
three other pieces of state still reset to their defaults on refresh:

1. **Initialized hardware disappears.** After a refresh the Hardware Status card
   shows the "Initialize Hardware" button again, as if no boards were connected.
2. **The concurrent-video button is no longer enabled.** The camera controls
   reset, so the video feature looks disabled even though the Pi is still
   recording.
3. **Start/Stop bookmark requests stop reaching the Pi.** After a refresh,
   pressing a sensor's Start/Stop no longer sends a bookmark to the Pi camera
   server, so those events are missing from the video.

All three are the same class of bug as the one PR #5 fixed, in state that was
not migrated onto the persistence mechanism.

### Root cause (verified)

Solara stores each module-level `solara.reactive` value **per kernel context**
(`solara/toestand.py`, `KernelStore._get_dict`). A refresh/reconnect hands the
browser a fresh context whose reactives all read their defaults. PR #5 solved
this for a chosen set of keys by holding an authoritative copy in a plain
module-global `session` dict (context-immune), mirroring writes into the
reactives via `set_session()`, and rehydrating the reactives from `session` on
every `Page` mount (`rehydrate_reactives_from_session`, called from a
`use_effect` in `recording_gui.py`).

The three broken pieces were never added to that mechanism:

- **Hardware** — `boards_connected` and `i2c_controllers`
  (`utils/state.py:44,47`) are written with bare `state.<x>.set(...)` in
  `components/hardware_status.py` (`initialize_hardware`, `disconnect_hardware`).
  Not in `session`, not in `_REACTIVE_FOR`, so `rehydrate` never restores them →
  a fresh context reads `{}` → the card falls into its "no boards" branch
  (`hardware_status.py:86`) and shows Initialize.
- **Camera** — `camera_enabled`, `camera_sensor_id`, `camera_host`,
  `camera_port`, `camera_video_filename`, `camera_disk_warning`,
  `camera_stall_warning`, `camera_status` are all written with bare `.set(...)`
  and are absent from the persistence mechanism → a fresh context reads defaults
  (`camera_enabled=False`, `camera_sensor_id=None`).
- **Bookmarks** — the Start/Stop bookmark calls gate on
  `state.camera_enabled.value and sensor_id == state.camera_sensor_id.value`
  (`components/sensor_card.py:149,203`) and `state.camera_enabled.value`
  (`components/session_controls.py:154,293`). After a refresh those read
  `False` / `None`, so the gate is never satisfied and no bookmark is sent.
  **Fixing camera persistence fixes bookmarks** — no separate change needed.

**Why the live hardware is still usable after a refresh:** the actual FT232H
I2C controller/port objects and `mpr121_manager` are held in **plain module
globals** (`ft232h_manager`, `mpr121_manager` in `hardware_status.py`, and the
same controller objects referenced inside the `i2c_controllers` dict). A browser
refresh does not touch the server process, so those USB handles stay open. Only
the per-context *reactive* pointing at them was lost. Re-mirroring the same live
references is therefore valid and requires **no USB re-scan** — which is also
what makes it safe to do during an active recording (a re-scan would re-open the
USB devices out from under the running acquisition loop).

## Goals

1. After a refresh, the Hardware Status card shows the connected boards, not the
   Initialize button.
2. After a refresh, the concurrent-video controls show their pre-refresh state
   (enabled/disabled, selected bookmark sensor, host/port).
3. After a refresh, Start/Stop still send bookmark requests to the Pi.

**Out of scope (stays per-context, transient UI — YAGNI):** `snapshot_image`,
`snapshot_error`, `snapshot_pending`, `show_snapshot_dialog`,
`show_test_dialog`, `test_plot_data`, `log_messages`.
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

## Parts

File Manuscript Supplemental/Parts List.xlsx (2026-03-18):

This parts lists is based off the CLiQR System from the Timme Lab (last updated March 2026). The quantity of parts is for a system of 24 Allentown Mouse Cages
Part Name | Vendor | Part # | Link | Qty | Price/Unit | Total Price | Extra Notes
METRO Wire Shelving Unit: 60 in x 24 in x 67 7/8 in, Dry, Quick-Adjust, 4 Shelves, Silver | Grainger | 2EWT4 | https://www.grainger.com/product/METRO-Wire-Shelving-Unit-60-in-x-2EWT4 | 1 | 716.68 | 716.68
Adafruit EVAL BOARD FOR FT232H | Digikey | Digikey #: 1528-1449-ND Adafruit #: 2264 | https://www.digikey.com/en/products/detail/adafruit-industries-llc/2264/5761217 | 4 | 14.95 | 59.8
Adafruit 2.5MM PITCH 2-PIN CABLE MATCHING | Digikey | Digkey #: 1528-4872-ND Adafruit #: 4872 | https://www.digikey.com/en/products/detail/adafruit-industries-llc/4872/13922052 | 24 | 0.95 | 22.8 | May want to purchase extras to keep as backups
Adafruit MPR121 TOUCH SENSE 12-KEY | Digikey | Digikey #: 1528-1038-ND Adafruit #: 1982 | https://www.digikey.com/en/products/detail/adafruit-industries-llc/1982/4990787 | 4 | 7.95 | 31.8
STEMMA QT Connector Cables | Adafruit | Adafruit #: 4210 | https://www.adafruit.com/product/4210 | 4 | 0.95 | 3.8
Computer (at least 5 usb ports) | Dell | Optiplex 7080 | https://www.dell.com/en-us/shop/desktop-computers/optiplex-7080-micro-desktop/spd/optiplex-7080-micro/cto01o7080mffus | 1 | 1200? | 1200 | Since starting the manuscript, Dell has stopped selling our particular model of Dell Optiplex 7080 (with the i7). The link shows the i5 version, which was a couple hundred dollars less than the i7 version, but I don't remember the exact price difference. The i5 version is currently $989
Currently available close alternative to Dell Optiplex 7080 |  |  | https://www.dell.com/en-us/shop/desktop-computers/dell-pro-micro-desktop/spd/dell-pro-qcm1250-micro |  |  |  | The closest option that is currently available has a much newer i7 (14700 instead of 10700), but it seems similar otherwise. It is selling new for 1313.51, which is definitely more than the version we have cost new, but not by too much.
VESA Mount Arms | Amazon |  | https://www.amazon.com/VIVO-Universal-Monitor-Removable-MOUNT-POLE01A/dp/B083F3RPRK/146-9757827-9727065 | 2 | 29.99 | 59.98 | One for the monitor, one for the keyboard tray
Stylus* | Amazon |  | https://www.amazon.com/Targus-Smooth-Standard-Stylus-AMM165US/dp/B0163STAKS?s=pc | 1 | 9.99 | 9.99
Solid core wire* | Digikey | 1175-2677-100-ND | https://www.digikey.com/en/products/detail/cnc-tech/3132-22-1-2000-001-1-TD/12749403 | 1 | 17.41 | 17.41
USB-A to USB-C Data Cables (2 pack) | Amazon |  | https://www.amazon.com/Anker-Charger-Charge-Charging-Samsung/dp/B0BPCZLFS4 | 2 | 7.99 | 15.98 | Need 2 packs of 2 cables (4 total)
Keyboard Mount | Amazon |  | https://www.amazon.com/VIVO-Laptop-Notebook-Platform-STAND-LAP2/dp/B00Z1VBIE0?gQT=2 | 1 | 29.99 | 29.99
Touchscreen monitor | Amazon | Asus VT229H | https://www.asus.com/us/displays-desktops/monitors/touch/vt229h/ | 1 | 209.35 | 209.35
Power Strip | Grainger | 52NY43 | https://www.grainger.com/product/Outlet-Strip-6-Outlets-52NY43 | 1 | 17.91 | 17.91
Wifi adapter | Amazon | TPLink AC1300 | https://www.amazon.com/USB-WiFi-Network-Adapter-Dongle/dp/B07P6N2TZH | 1 | 17.55 | 17.55
USB Hub | Amazon |  | https://www.amazon.com/Extender-Splitter-MacBook-Chromebook-Pixelbook/dp/B0DKFF6SVX | 1 | 6.88 | 6.88 | Used by peripherals like touchscreen, keyboard and wifi adapter
Parts Fabricated in Lab
PLA Filament | Digikey | 1942-RM-PL0321-ND | https://www.digikey.com/en/products/detail/lulzbot/RM-PL0321/16186609 | 1 | 20.99 | 20.99
3D Printed Sippers Holders |  |  |  | 24 |  |  | May want to print extras to keep as backups
3D Printed Board Mount (MPR121) |  |  |  | 4 |  |  | The board mount prints are slightly different
3D Printed Board Mount (FT232H) |  |  |  | 4
M2.5 Threaded Inserts | Amazon | ASIN: B0CS6YVJYD | https://www.amazon.com/HANGLIFE-Heat-Set-Threaded-Printing-Components/dp/B0CS6YVJYD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 | 1 | 8.99 | 8.99
M2.5 X 0.45 Screws for mounting boards to 3D print holders | Grainger | 6CY85 | https://www.grainger.com/product/Socket-Head-Cap-Screw-M2-5x0-6CY85 | 1 | 4.68 | 4.68
Copper Tape | Amazon | B09WGYP2VR | https://www.amazon.com/dp/B09WGYP2VR?ref=fed_asin_title | 1 | 6.89 | 6.89
Sippers
10 mL seriological pippette | Corning | 4488 | https://ecatalog.corning.com/life-sciences/b2c/US/en/Liquid-Handling/Pipets/Serological-Pipets/Stripette%E2%84%A2-Serological-Pipets/p/4488 | 1 | 138.5 | 138.5 | One case contains 200 pipets
Rubber Stopper | Amazon | ASIN: B00V6V9S00 | https://www.amazon.com/High-Temp-Silicone-Painting-Supplies/dp/B00V6V9S00 | 1 | 8.95 | 8.95 | 50 pack
Heat Shrink Tubing | Grainger | 4WMT2 | https://www.grainger.com/product/INSULTAB-Heat-Shrink-Tubing-4WMT2 | 1 | 52.89 | 52.89 | 5 pack of 4 ft rolls (lots of extra)
Drinking Tubes (5/16" Diameter) | Ancare | TD-102 | https://www.ancare.com/products/drinking-tubes-5-16-diameter?variant=41326987313338 | 24 | 3.65 | 87.6 | May want to purchase extras to keep as backups
Tools/Equipment
Hot Glue Gun | Amazon | UPC: 793029997412 ASIN: B077XBZGLP | https://www.amazon.com/dp/B077XBZGLP?ref=fed_asin_title | 1 | currently unavailable on amazon
Dremel | Grainger | 14H446 | https://www.grainger.com/product/DREMEL-Rotary-Tool-Kit-1-2-A-Current-14H446 | 1 | Product now discontinued
Heat gun | Brand: Milwaukee Vendor: Amazon | Part #: ‎8975-6 ASIN: B00004TI25 | https://www.amazon.com/dp/B00004TI25?ref=fed_asin_title | 1 | 98 | 98
Soldering System (Hakko FX888DX-010BY) | Amazon | UPC: 641328089379 ASIN: B0D4DJW54S | https://www.amazon.com/Hakko-FX888DX-010BY-Digital-Soldering-Station/dp/B0D4DJW54S?nsdOptOutParam=true | 1 | 117.83 | 17.83
Soldering Tips/Inserts | Amazon | ASIN: B0CHDJWKR2 | https://www.amazon.com/ruthex-Bundle-Threaded-Assortment-Soldering/dp/B0CHDJWKR2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 | 1 | currently unavailable on amazon
Solder Wire with Flux | Amazon | B07XKHNN2Z | https://www.amazon.com/dp/B07XKHNN2Z?ref=fed_asin_title | 1 | 8.53 | 8.53
Optional
squeeze bottles (pack of 4) | Fisher Scientific | FB0340922D | https://www.fishersci.com/shop/products/translucent-white-wash-bottles-2/FB0340922D?searchHijack=true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 | 1 | 48.67 | 48.67
sand paper of sorts | Amazon | B08YQYWZFM | https://www.amazon.com/3M-Precision-Faster-Sanding-24001TRI-F-B/dp/B08YQYWZFM | 1 | 9.79 | 9.79
Lab tape | Fisher Scientific | NC0647069 | https://www.fishersci.com/shop/products/rainbow-tape-3-4-w-x-14yd-16pk/NC0647069#?keyword=NC0647069 | 1 | 74.5 | 74.5
Zip Ties | Amazon | B0C2Z4L3S6 | https://www.amazon.com/Assorted-Sizes-12-Resistant-ANOSON/dp/B0C2Z4L3S6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 | 1 | 6.99 | 6.99
Total Cost |  |  |  |  |  | 3013.72

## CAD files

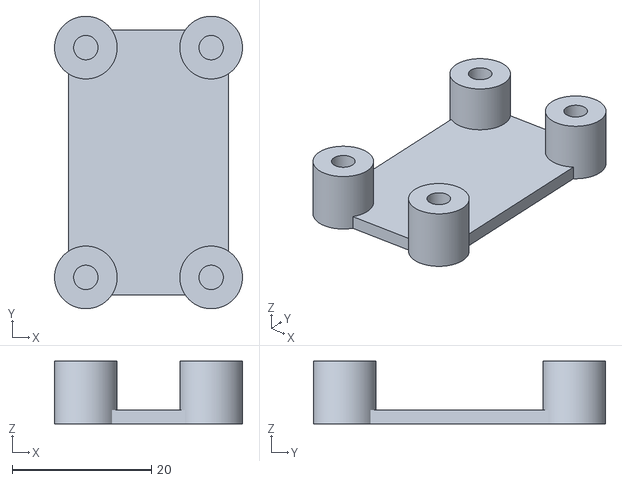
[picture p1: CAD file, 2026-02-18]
3D Print Files/FTBoardMount.stl
27.0 x 42.0 x 9.00

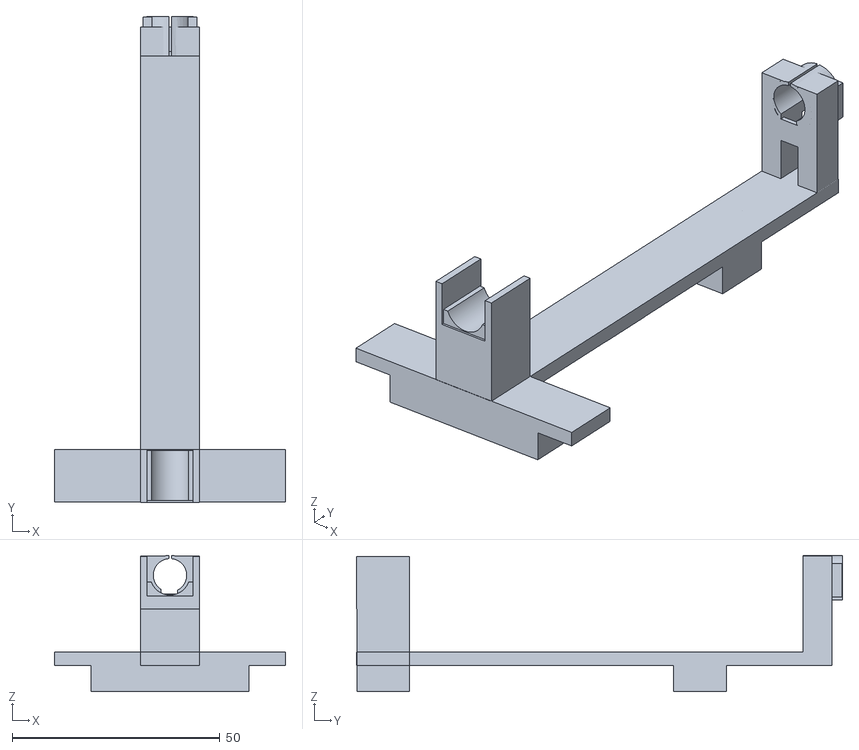
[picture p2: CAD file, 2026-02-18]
3D Print Files/AllentownSipperHolderRingContact.stl
55.6 x 116.9 x 32.8

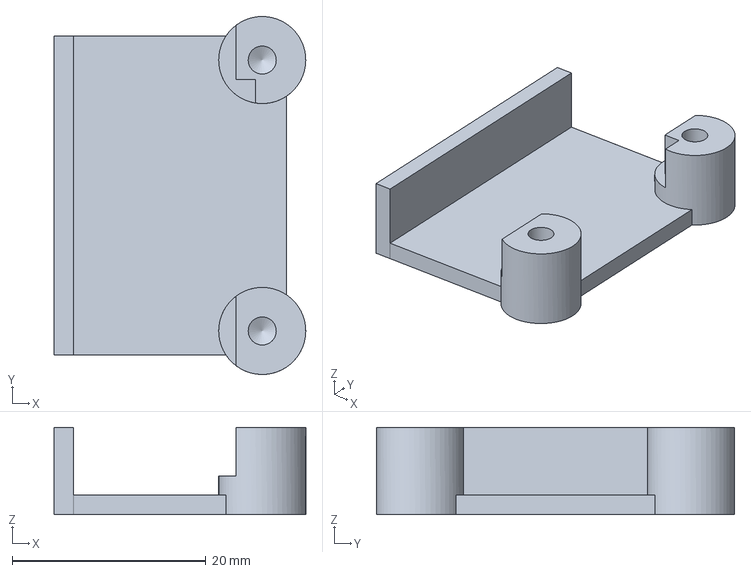
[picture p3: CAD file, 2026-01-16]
3D Print Files/MPR121_mount_with_cutouts.FCStd
26.0 x 37.0 x 9.00 mm

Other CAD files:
3D Print Files/MPR121_mount_with_cutouts.stl

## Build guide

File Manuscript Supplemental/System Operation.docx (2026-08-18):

# System Operation

This section reproduces the Timme Lab CLiQR protocol document, including detailed instructions about system operation.

Note: This protocol is for the lickometry system designed and implemented in Spring 2025 (protocol last updated 14 August 2026). The system consists of a Dell Supermicro desktop PC running the CLiQR GUI (https://github.com/timmelab/cliqr) to communicate with MPR121 capacitive touch sensors (with communication facilitated by FT232H boards). Each pair of FT232H+MPR121 can record from 6 cages, for a total of 24 cages currently (with 4 pairs of boards).

## Equipment/Reagents

- 24 Sipper Holders (should be attached to the system already)
- 24 Graduated Sippers (with rubber stoppers)
- Dell Supermicro Desktop
  - As mentioned in the note above
  - Already attached to the rack
- Scale + Beaker
  - For recording animal weights
  - If the animals had their weights previously recorded the same day (e.g. before forced swim testing in the morning), you can simply record those weights in the UI and skip the scale+beaker
- Phone/timer
  - The system will record continuously until stopped, so you’ll want something to time the run
- 1 L of 20% Ethanol (210 mL of ethanol per 790 mL of water, since we have 95% ethanol)

## Starting a Session

1. The first step should be filling the graduated sippers with 20% ethanol solution so that it’s easier to quickly start the animals drinking in sequence (without long gaps between start times).
  I. Fill the sippers with ~10 mL and ensure that the rubber stoppers are firmly inserted.
  II. Filling should be done with a finger or palm covering the tip of the sipper, because the liquid will quickly leak out otherwise.
  III. Once the rubber stopper is inserted, ensure that the sipper is not leaking excessively by uncovering the tip while holding the sipper over a sink or the drain in the floor.
  IV. If the sipper leaks (more than 1 or 2 drops), double check the stopper. If that doesn’t solve the issue, set that sipper aside.
2. Power on the computer (if necessary) and log in to the TimmeLab account (ask if you don’t know the password)
3. Double-click on the desktop shortcut with the name “CLiQR” and the recording interface should display after a few seconds
4. At this point, your screen should look roughly like Figure S18

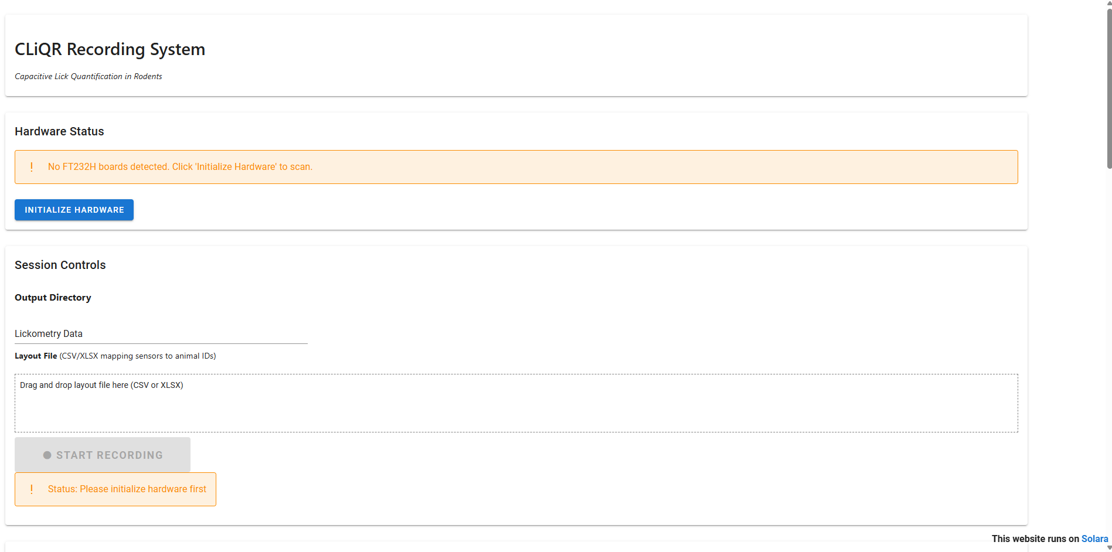
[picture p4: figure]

Figure S18. Initial CLiQR GUI Window Appearance

5. Begin by pressing the “Initialize Hardware” button, and the system will detect and configure all of the capacitive sensors. The resulting window should look like Figure S19

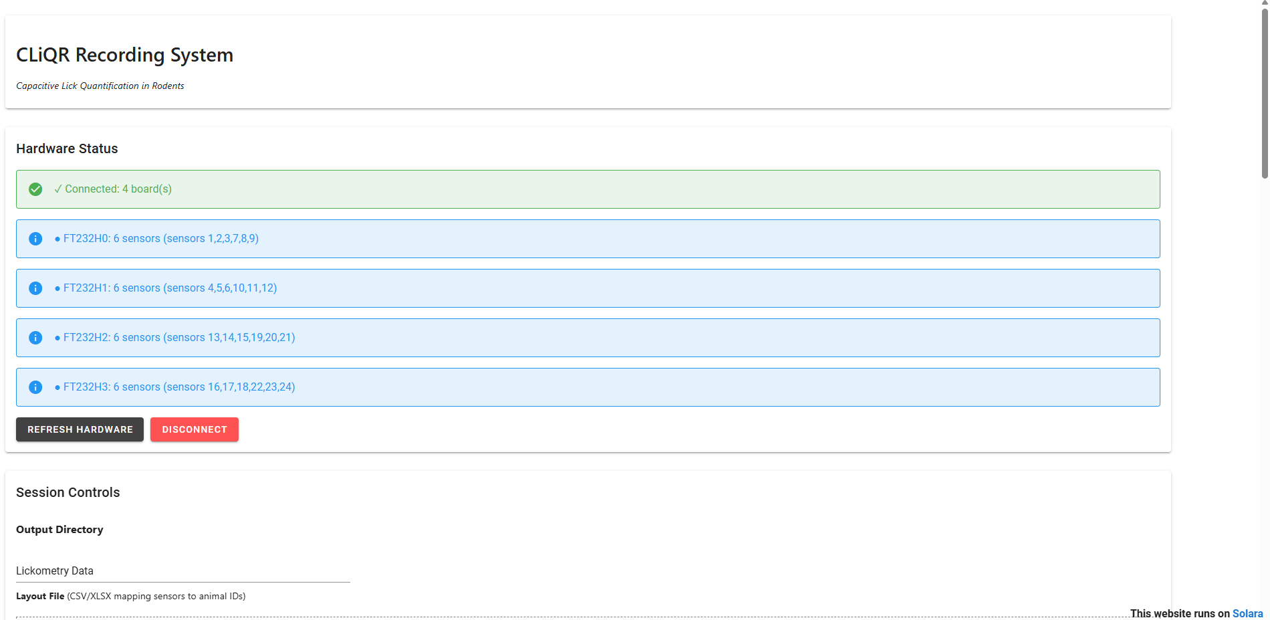
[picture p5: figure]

Figure S19. CLiQR GUI after hardware initialization. Notice that all 4 FT232H boards are listed, along with the sensors each controls.

6. The “Output Directory” text entry box defaults to “Lickometry Data” (a subdirectory inside the CLiQR directory, just for storing data recordings)
  I. This can be changed to include the cohort identifier, like “Lickometry Data/AEW6”, which will create a subdirectory for that cohort inside of the lickometry data subdir.
7. The “Layout File” section is for assigning animals to sensors so that it stays consistent between drinking sessions. On the first session of a cohort, this will need to be created (and it will be reused each day).
  I. This can be created in Excel or just a text editor.
  II. The format should be sensor_number, animal_id and each sensor should be on a new line.
  III. For instance, 1,AEW6-1 shows the animal ID on sensor 1.
  IV. Ensure the file is saved as csv and drag-and-drop it onto the cage layout upload box in the CLiQR GUI.
  V. The resulting screen should look like Figure S20

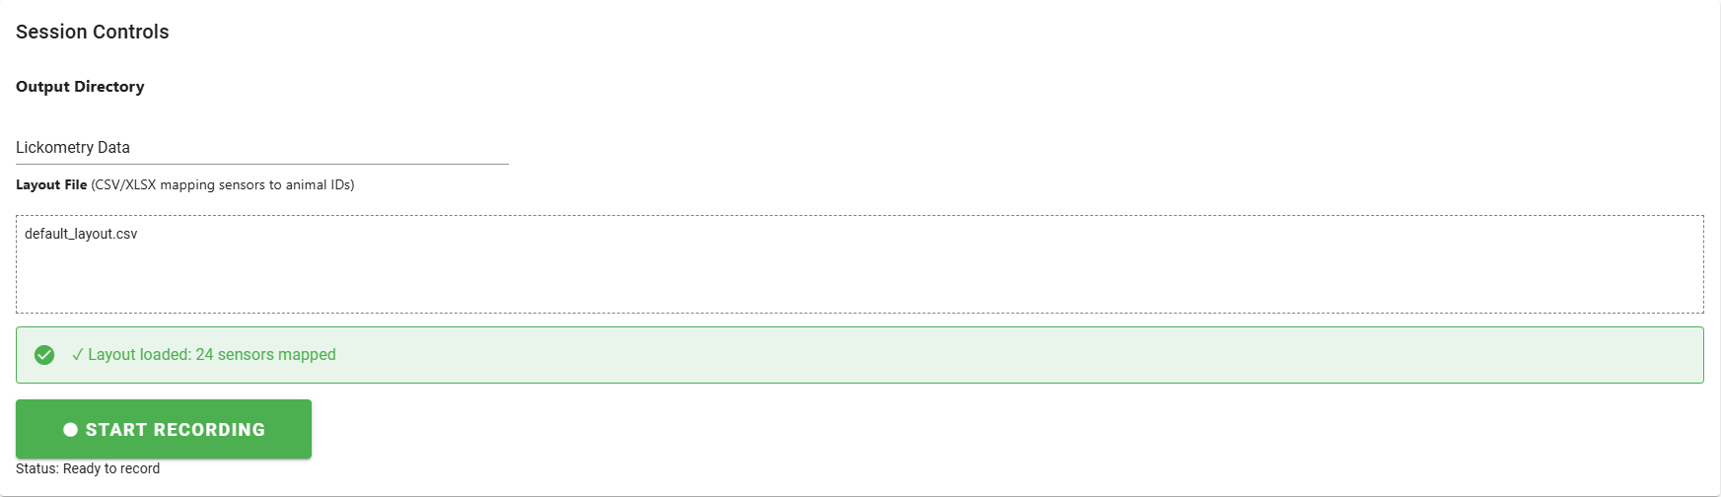
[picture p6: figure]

Figure S20. Layout file upload confirmation.

8. If not already done earlier in the day, weigh each animal using the scale and beaker
9. Record the animal weights (whether directly measured just now, or from the data sheet with animal weights from earlier) in the “Weight” input box corresponding to the correct sensor for each animal.
  I. Now, you should place the animal cages on the rack (6 cages per shelf). The sensors are numbered 1-6 (top shelf, left to right), 7-12 (2nd shelf), 13-18 (3rd shelf), 19-24 (bottom shelf). The recording interface matches this layout as though you are standing in front of the rack looking at it.
  II. You will need to move the sipper holder (Figure S21) out of the way before placing the cage on the rack

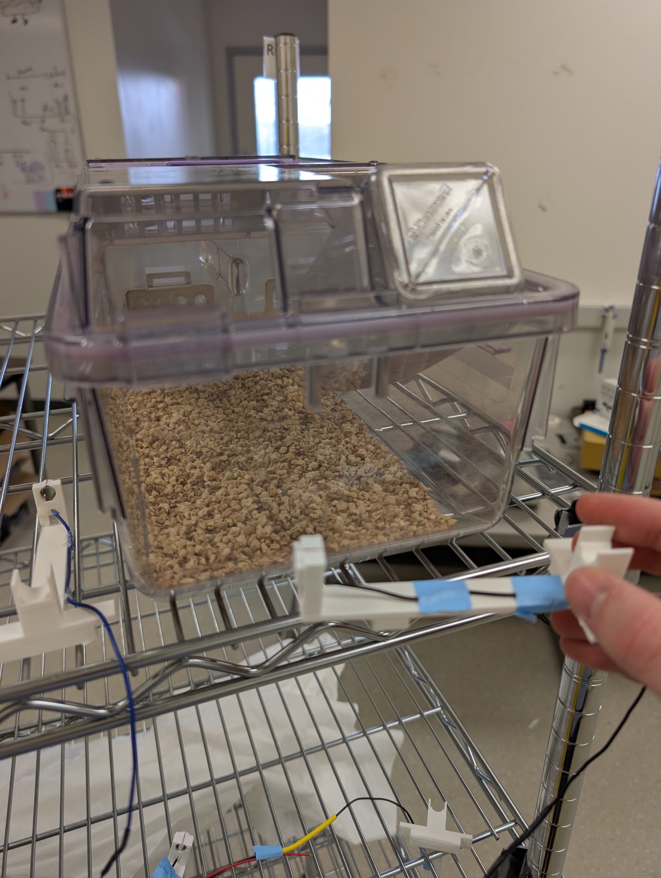
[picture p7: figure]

  III. Once you have placed the cage on the rack, move the large water sipper out of the way (it can be placed on top of the cage lid as shown in Figures S22). Now, place the sipper holder on the cage lid (Figure S22).

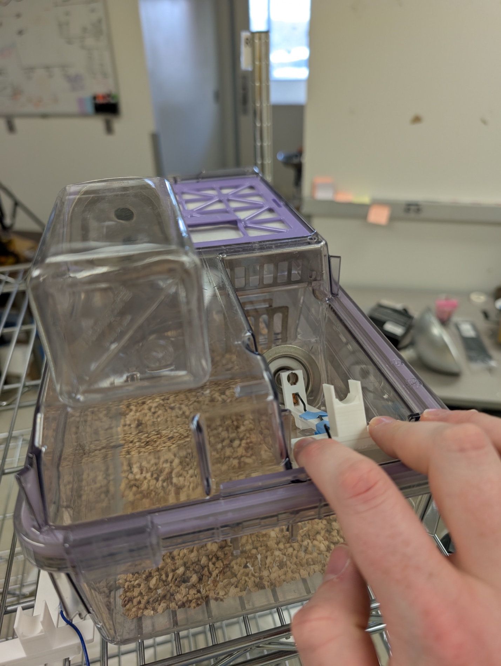
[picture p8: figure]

Figure S21. Move the sipper holder out of the way and place the cage on the rack.

Figure S22. Place the sipper holder on the cage, moving the large water sipper out of the way.

  IV. Ensure that you have placed the correct sipper holder by checking that the number written on tape wrapped around the attached wires matches the sensor number for that animal

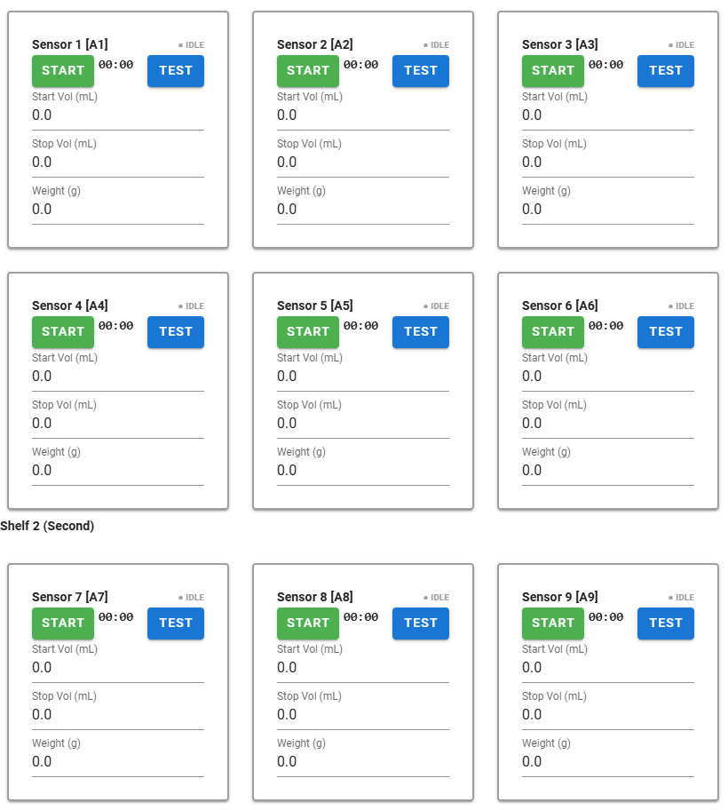
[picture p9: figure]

10. Once the cages are situated, press the “Start Recording” button. The sensor grid will change to look like Figure S23 (note the colored start and test buttons).

Figure S23. Sensor grid while recording, note the colored buttons (the buttons are greyed out when not recording).

11. Starting with sensor 1, place the sippers in the holders one at a time while testing that the signal is good and recording volumes
  I. Insert the sipper tip through the ring on the sipper holder and the metal opening on the cage lid (Figure S24)

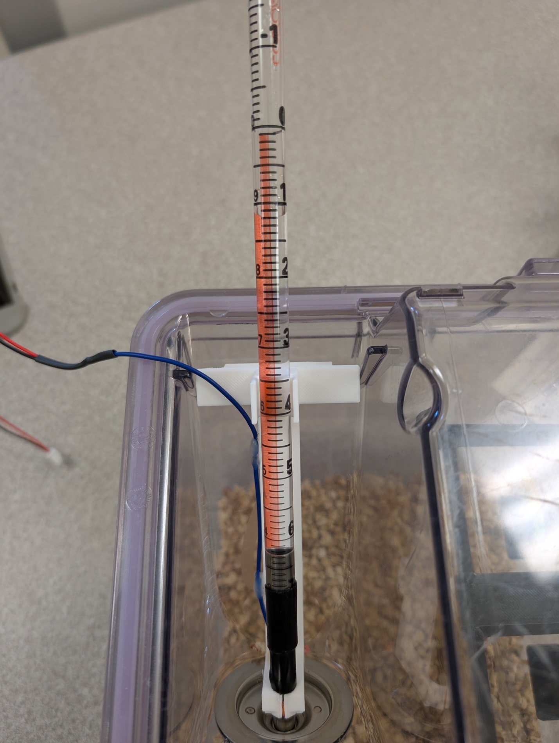
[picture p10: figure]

Figure S24. Sipper inserted through sipper holder ring and cage lid.

  II. Test the signal
    i. Three firm presses with an ungloved finger on the metal ring through which we push the sipper

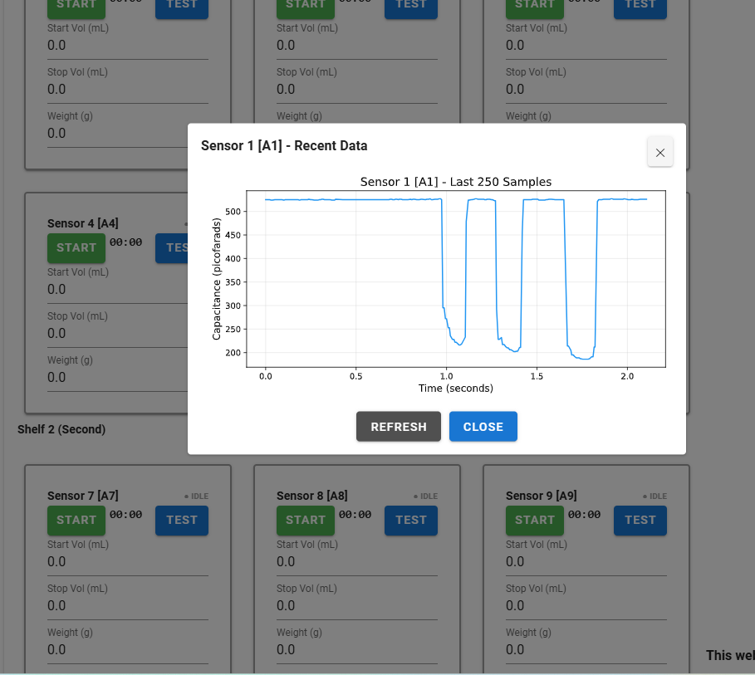
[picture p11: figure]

    ii. Wait a second (for the data to be saved), then press the “Test” button next to the sensor you’re testing in the UI (Figure S25)

Figure S25. This is an example of a good test that shows a strong signal. We expect a drop greater than 100 pF from each finger press

    iii. You should be able to clearly distinguish all three finger presses
    iv. If the signal isn’t good, there are a couple of things to try:
      1. Use a small amount of alcohol to wipe the copper tape of the sipper holder and the sipper tip where it meets the holder (dirtiness can degrade the signal)
      2. If you cannot get the signal to look good through fiddling, make a note of which sensor/animal in the comments box at the bottom of the CLiQR GUI and move on
  III. Press the “Start” button corresponding to the sensor you just tested
  IV. Record the sipper volume in the “Start Vol” input box. See Figure S26. The volume should be read by the same person each time, both when starting and stopping a run, to minimize inter-person variability of readings. The sippers should typically be filled to around 10 mL, but the change in volume between starting and stopping volumes is much more important than the absolute starting point (a start reading of 2 mL and stop at 1.9 mL will give the same results as a start at 10 mL and stop at 9.9 mL in our analysis). Ensure that volumes are read to the nearest 0.05 mL (the best resolution we can read with graduation markings at 0.1 mL intervals).

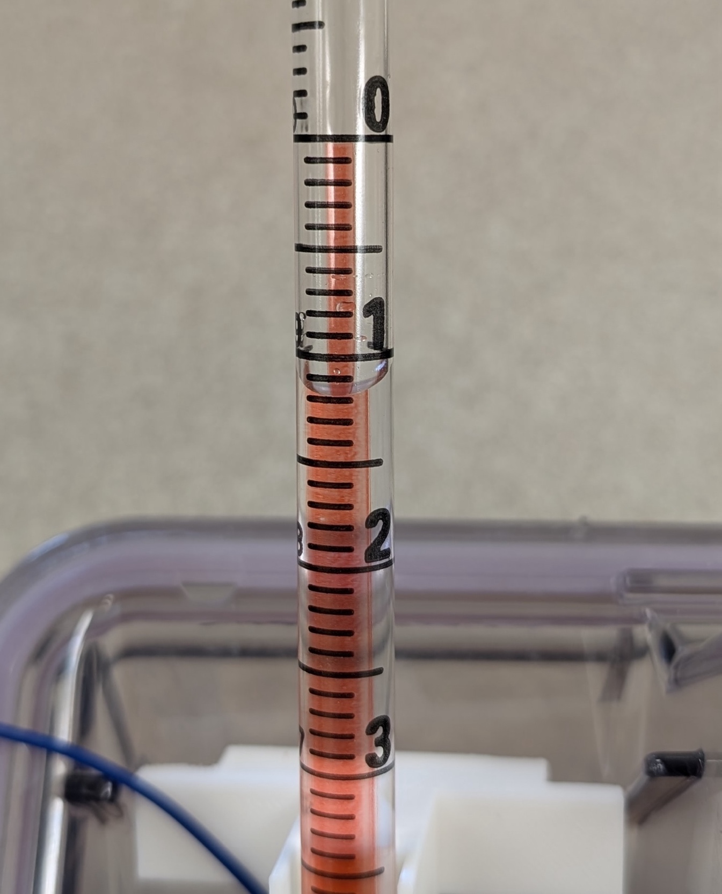
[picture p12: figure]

Figure S26. This sipper would be read as 8.8 mL. It’s difficult to see here, but there are alternative labels: 0 = 10, 1 = 9, 2 = 8, etc. So we read this as 1.2 mL below 10 = 8.8 mL.

12. Once you have completed the above steps, set a timer for 2 hours
13. Place the “Experiment in Progress” sign on the rack

## Ending a Session

14. Wait outside vivarium until the 2 hours are complete
15. Take “Experiment in Progress” sign down
16. Starting with sensor 1 again:
  I. Press the “Stop” button corresponding to the correct sensor
  II. Read and record the volume of liquid remaining in the sipper in the “Stop Vol” input box
  III. Carefully remove the sipper from the sipper holder and set aside
  IV. Remove the sipper holder from the cage lid and place it on the rack beside the cage
  V. Replace the large water bottle
  VI. Transfer the cage back to the other rack
17. Once you’ve stopped the sensors, press the large “Stop Recording” button to finalize the data files
18. The data has been saved in the directory you selected for the “Output Directory”, which defaults to CLiQR\Lickometry Data\
  I. raw_data_{date of recording}.h5
  II. Copy the data file to the lab drive (L:\). The specific directory will depend on the current experiment. If you’re unsure, please ask!
  III. You can leave the files on the rack computer also, so that we have multiple copies (just in case)
19. Close the browser window and the PowerShell window (should be running behind the browser), then put the computer to sleep
20. Dump out the remaining fluid from the sippers

## Note!

If there are any issues during operation of the system, please write a note about the issues in the “Comments” box found at the very bottom of the GUI window. See Figure S27.

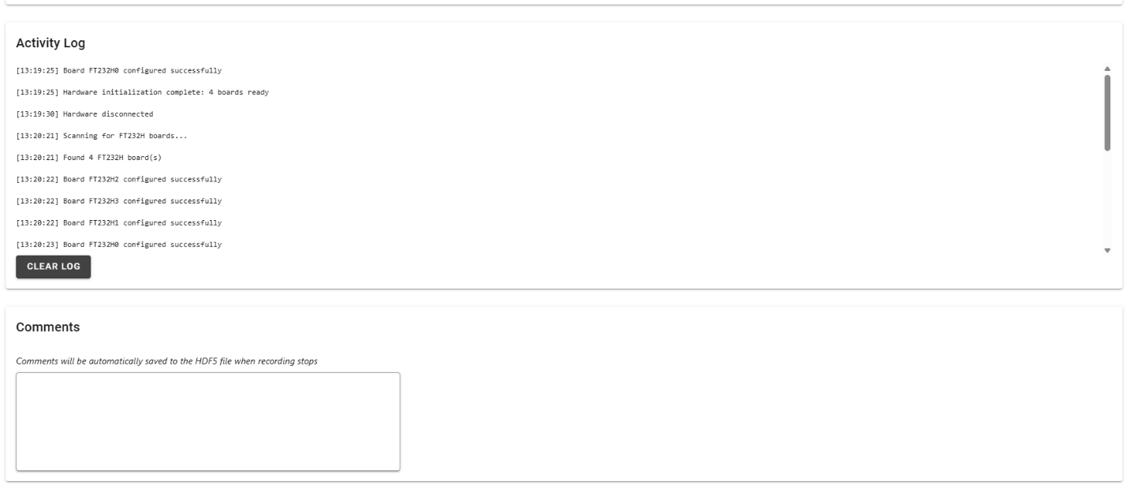
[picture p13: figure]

Figure S27. Activity log (for debugging) and comments section are found at the very bottom of the CLiQR GUI window.

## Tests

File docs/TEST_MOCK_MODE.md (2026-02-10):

# Testing CLiQR GUI with Mock Hardware

## Quick Start

To test the GUI without physical hardware:

```bash
# Activate the conda environment
conda activate cliqr

# Run the app with mock hardware
solara run recording_gui_mock.py
```

The app will be available at http://localhost:8765

## What Mock Mode Provides

Mock mode simulates:

1. **4 FT232H boards** (FT232H0-3)
2. **24 MPR121 sensors** (6 per board)
3. **Realistic capacitance data** with:
   - Baseline values around 500
   - Periodic variations simulating licking patterns
   - Random noise (±10 counts)
4. **All HDF5 operations** (files are created normally)

## Testing Checklist

Use this checklist to verify all functionality:

### Hardware Initialization
- [ ] Click "Initialize Hardware" button
- [ ] Verify all 4 boards show as connected
- [ ] Check activity log for initialization messages

### Recording Session
- [ ] Select an output directory
- [ ] Click "START RECORDING"
- [ ] Verify filename is generated with timestamp
- [ ] Check that sensor START buttons are now enabled

### Individual Sensors
- [ ] Click START on sensor 1
- [ ] Verify status changes to RECORDING (green)
- [ ] Wait 60+ seconds, verify timer updates
- [ ] Enter start volume, stop volume, and weight
- [ ] Click STOP
- [ ] Verify status returns to IDLE (gray)
- [ ] Check activity log for start/stop messages

### Volume/Weight Inputs
- [ ] Enter values in start volume field
- [ ] Enter values in stop volume field
- [ ] Enter values in weight field
- [ ] Verify values are saved when sensor is stopped

### Session Comments
- [ ] Enter text in comments area
- [ ] Stop recording session
- [ ] Verify comments are saved to HDF5 file

### Complete Recording Session
- [ ] Start recording
- [ ] Start 2-3 sensors
- [ ] Let them record for at least 5 minutes
- [ ] Stop individual sensors
- [ ] Click "STOP RECORDING"
- [ ] Check that HDF5 file was created

### HDF5 File Verification

After a test recording session, verify the HDF5 file structure:

```python
import h5py

# Open the generated file
with h5py.File('raw_data_YYYY-MM-DD_HH-MM-SS.h5', 'r') as f:
    # Check structure
    print("Groups:", list(f.keys()))

    # Check a board
    board = f['board_FT232H0']
    print("Sensors:", list(board.keys()))

    # Check a sensor
    sensor = board['sensor_1']
    print("Datasets:", list(sensor.keys()))

    # Verify data
    if 'cap_data' in sensor:
        print("Samples recorded:", len(sensor['cap_data']))
        print("First 10 samples:", sensor['cap_data'][:10])

    # Check metadata
    if 'start_time' in sensor:
        print("Start time:", sensor['start_time'][()])
    if 'stop_time' in sensor:
        print("Stop time:", sensor['stop_time'][()])
    if 'start_vol' in sensor:
        print("Start volume:", sensor['start_vol'][()])
    if 'stop_vol' in sensor:
        print("Stop volume:", sensor['stop_vol'][()])
    if 'weight' in sensor:
        print("Weight:", sensor['weight'][()])

    # Check comments
    if 'comments' in f:
        print("Comments:", f['comments'][()])
```

## Expected File Structure

```
/comments (dataset)
/board_FT232H0/
  sensor_1/
    cap_data (dataset with samples)
    time_data (dataset with timestamps)
    start_time (scalar)
    stop_time (scalar)
    start_vol (scalar)
    stop_vol (scalar)
    weight (scalar)
  sensor_2/
    ...
/board_FT232H1/
  ...
```

## Known Limitations

Mock mode does NOT test:
- Real USB communication errors
- I2C address detection failures
- MPR121 configuration issues
- FT232H driver problems (Windows Zadig)
- Actual capacitance sensing

For these scenarios, testing with real hardware (Task #11) is required.

## Troubleshooting

**Problem:** App won't start
- Check that solara is installed: `pip install solara`
- Check Python version: `python --version` (should be 3.13)

**Problem:** Import errors
- Ensure you're in the correct directory (CLiQR-GUI)
- Activate conda environment: `conda activate cliqr`

**Problem:** HDF5 file not created
- Check file permissions in output directory
- Verify output directory exists
- Check activity log for error messages

**Problem:** Sensor timers not updating
- Wait at least 60 seconds (timers update every minute)
- Check browser console for JavaScript errors

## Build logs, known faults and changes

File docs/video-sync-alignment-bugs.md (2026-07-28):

# Video ↔ Capacitance Alignment Bugs (acquisition anchor)

**Date:** 2026-07-14
**Reference recording:** `Lickometry Data/ACG-26-3/raw_data_2026-07-13_11-59-47.{mp4,h5,txt}`

## Symptom

In the side-by-side demo clip (`make_sync_video.py`) the mouse video ran ahead
of the capacitance trace by a roughly constant ~2.5 s: a lick was visible in the
video panel before its capacitance deflection reached the centered dot.

## Where the error actually is

Not in the clip renderer. `make_sync_video.py`'s math is self-consistent — both
panels are driven by session time τ (τ = 0 ≡ `start_time`):

- **Cap side:** `data_analysis.filter_data` zero-bases `time_data` at `start_time`.
- **Video side:** frame session = `sidecar_pts − video_base`, with
  `video_base = sidecar[frame_index] − sidecar[0]`.
- The mp4-internal PTS (read via `-copyts` + ffprobe) vs the `.txt` sidecar PTS
  (used for `video_base`) drift only ~0.02 s over 30 s — negligible.

So the two panels line up **iff** the anchor holds: *the bookmarked frame
coincides with `start_time`*. That single link was wrong, for two reasons on the
**acquisition** side. `make_sync_video` faithfully propagated the error.

### Bug 1 — bookmark round-trip latency (dominant, the ~2.5 s)

`components/sensor_card.py` stamps `start_time = time.time()` on the host, then a
few lines later calls `client.bookmark()`, a synchronous round-trip to the Pi.
The Pi returns its *current* frame count, captured L seconds later (one-way
latency). So the bookmarked frame actually occurred at `start_time + L`, but the
pipeline treated it as `start_time`. Every video frame was therefore labeled L
seconds too early → the video panel leads the trace by L (~2.5 s here).

**Worse, the blocking call also destroyed data.** `start_sensor` runs on the
Solara asyncio event loop — the *same* loop that drives `recorder.record_sensors`
(`recording/recorder.py:71`, `await asyncio.sleep(0)` per iteration). A
synchronous socket round-trip on that loop freezes the loop, so **no sensor is
sampled for the whole round-trip**. Confirmed on the reference file: **every one
of the 24 sensors on all four boards has an identical ~5.019 s gap at
`start_time`** — by far the largest gap in the 8127 s recording (next largest
0.23 s). The full round-trip (~5 s) is the gap; the one-way (~2.5 s) is the video
lead. (The camera `start_session` call is *not* the culprit: the bookmark frame
sits ~32 s into the video, so `start_session` ran ~32 s before `start_time`.)

L was **not recorded anywhere**: only `video_frame_index` and `video_pts` were
persisted. The cap clock is host-unix; the video clock is Pi `SensorTimestamp`;
with no second shared event, L could not be recovered post-hoc — which is why no
display change fixed it and a manual `--sync-offset` was the only lever for an
already-captured file.

### Bug 2 — off-by-one in the bookmark (~8 ms, minor)

`pi/camera_backend.py::_on_frame` writes a frame's timestamp to the sidecar
(0-based line = frame index) and *then* increments `_frame_count`. `bookmark`
returned `frame_index = _frame_count` (the next, not-yet-written frame) while
`pts = _last_frame_ts_ns` (the frame just written, `_frame_count − 1`). So
`video_frame_index` pointed one frame past the pts it was paired with.

## Fixes applied (this change)

0. **Non-blocking bookmark (stops the data loss)** — `components/sensor_card.py`
   now runs the bookmark round-trip on its own `daemon` thread (mirroring the
   existing stop-path pattern in `session_controls.py`) instead of on the event
   loop, so `record_sensors` keeps sampling during the round-trip and the
   ~5 s acquisition gap disappears. `write_video_metadata` is already h5-lock
   guarded; `start_sensor` returns the thread so tests can join it.
   (`tests/test_camera_integration.py::test_bookmark_does_not_block_the_caller`)

1. **Off-by-one** — `pi/camera_backend.py::bookmark` now returns
   `frame_index = _frame_count - 1`, matching the reported `pts`.
   (`tests/test_camera_session_lifecycle.py::test_bookmark_index_and_pts_describe_same_frame`)

2. **Record the latency** — the bookmark round-trip is now bracketed with host
   wall-clock, and the Pi clock is persisted, so L is measurable from the file:
   - `components/sensor_card.py` captures `host_before`/`host_after` around
     `client.bookmark()` and forwards them plus `pi_monotonic`.
   - `recording/recorder.py::write_video_metadata` writes new per-cycle
     datasets: `video_pi_monotonic`, `video_bookmark_host_before`,
     `video_bookmark_host_after` (each omitted when the caller doesn't supply it,
     so older callers are unaffected).
     (`tests/test_video_metadata.py`, `tests/test_camera_integration.py`)

   Recovery formula for a future recording:
   `L ≈ (host_before + host_after) / 2 − start_time`, and the corrected video
   anchor adds L to every frame's session time (equivalently, subtracts L from
   `video_base`).

3. **Consume the latency in the renderer** — `make_sync_video.py::load_recording`
   reads the bracket (via `bookmark_latency()`) and stores `rec.bookmark_latency`
   (0.0 when the fields are absent). `render_clip` corrects the anchor with
   `video_base_eff = rec.video_base − rec.bookmark_latency`, used for both frame
   trimming and per-frame timing, so a recording that carries the bracket aligns
   with no manual `--sync-offset`. `--sync-offset` remains only as a residual
   nudge. (`tests/test_make_sync_video.py`)

## Renderer bug — decode/pts frame-count drift (separate from the anchor)

**Symptom.** Two clips of very different length covering the same session showed
the *same* capacitance trace but a *different* video frame (~1 s apart, growing
with clip length) — a per-clip inconsistency the constant anchor offset can't
explain.

**Cause.** `make_sync_video.TrimmedFrameSource` times each frame by the ffprobe
pts list (`frame_sess`) but *counts* frames by imageio's sequential decode. This
footage is VFR (coded 240 fps, real ~120); imageio's default reader forces CFR
and **duplicates** frames, so it decodes more frames than the pts list has (e.g.
37200 vs 37066 over 300 s). Each duplicate advances the decode counter without a
matching pts, slipping the frame↔session map ~1 s per ~300 s — worse the longer
the clip, so two clips of different length disagree at the same session.

**Fix.** Open the reader in passthrough (`imageio.get_reader(..., output_params=
["-vsync", "0"])`) so exactly one decoded frame maps to each pts entry. Verified:
a 200 s clip and a 10 s clip now show the identical video frame at the same
session (0.0000 s difference). (`tests/test_make_sync_video.py::
test_trimmed_frame_source_decode_matches_pts`)

## Correction (2026-07-16) — the latency was the END of the bracket, not the midpoint

**Symptom.** A new finger-touch test recording
(`Lickometry Data/raw_data_2026-07-16_09-56-26`, which *does* carry the host
bracket, so `latency` = 2.50 s was applied automatically) still showed the video
leading the trace by ~2.5 s in `make_sync_video`. The midpoint correction removed
only half the true lag.

**Root cause.** `bookmark_latency` placed the bookmarked frame at
`(host_before + host_after) / 2`, which is right only if the round-trip delay is
symmetric *network* latency. It isn't. The round-trip on this file is **4.71 s** —
that is the Pi blocked/queued, not the wire. `camera_backend.bookmark()` reads
`_last_frame` when the call *runs* on the Pi, which is at the **end** of the
round-trip (~`host_after`), and the camera kept capturing during the block, so
`_last_frame` advanced the whole 4.7 s. Proof from the file itself: `pi_monotonic`
(bookmark exec, Pi clock) − `video_pts` (grabbed frame, Pi clock) = **0.016 s**, so
the frame was grabbed ~16 ms before exec ≈ `host_after`, not 2.5 s before it.

**Evidence.** Cross-correlating the video's per-frame motion energy against
|d cap/dt| over the 9 rhythmic finger presses: residual video-lead **+2.41 s**
with the midpoint latency (2.50 s), **+0.05 s** with `host_after − start_time`
(4.86 s), **+0.07 s** with `host_after − start_time − (pi_monotonic − video_pts)`
(4.84 s).

**Fix.**
- `bookmark_latency(host_after, start_time, pi_monotonic=None, pts=None)` now
  returns `(host_after − start_time) − (pi_monotonic − pts)` via the new
  `_frame_host_time` helper (the `pi_monotonic − pts` gap is dropped when the Pi
  clocks aren't recorded, leaving `host_after − start_time`).
- `VideoAnchor.drift_slope` uses the same end-of-bracket host time at **both**
  bookmark endpoints (was the midpoint at each).
- `VideoAnchor` gained `pi_monotonic`/`video_pts` (start) and
  `stop_pi_monotonic`/`stop_pts` (stop); `read_video_anchor` reads them.
- `recorder.write_video_metadata` now also persists `video_stop_pi_monotonic`;
  `sensor_card.bookmark_stop` forwards it. (Start already persisted
  `video_pi_monotonic` + `video_pts`.)
- `false_positive_analysis.alignment_from_bookmark` updated to the same formula
  and gained an optional `pi_monotonic` arg.
- Tests updated in `tests/test_trimcrop.py`, `test_make_sync_video.py`,
  `test_crop_video.py`, `test_bookmark_alignment.py`.

**Residual.** The only unmodelled term is the Pi→host response one-way latency
(~ms). No manual `--sync-offset` is needed for recordings that carry the bracket.

## Bug 5 — cropping by re-encode regenerated the PTS (2026-07-28)

**Symptom.** Rendering with a crop drifted the video later and later against the
trace (~1.6 s late on a ~6300 s clip), exactly the pre-framerate-fix behavior —
but only when `crop_video.py` was run first. The same clip rendered uncropped
stayed within 1 frame.

**Root cause.** The old flow re-encoded the crop into `<base>_cropped.mp4`
(`trim_and_crop`), and `make_sync_video` timed that file. Re-encoding to apply the
crop filter REGENERATES the presentation timestamps onto a fresh CFR grid: wrong
phase (a crop frame's `pts_time` no longer lands on the original frame grid — off
by a non-integer number of frames) and wrong rate (the muxer resets
`avg_frame_rate` from the true ~120.0048 fps to a flat `120/1`, and default
`-fps_mode cfr` even drops ~1 frame per 25k to hit it). `probe_frame_session_times`
recovers each frame's original container ordinal with `round(pts_time * rate)` to
index `container_pts_ns` (the original per-frame `SensorTimestamp` sidecar); on a
re-encoded file both `pts_time` and `rate` are wrong, so the lookup returns the
wrong capture time. The uncropped path never re-encodes (`subclip_copy` is a
stream copy that preserves the original PTS and rate), which is why it aligned.

**Evidence.** On `raw_data_2026-07-27`, a re-encoded crop reports
`avg_frame_rate = 120/1` and its clip frames' `pts_time` sit off the original grid
by a non-integer frame count; `-fps_mode passthrough` recovers the true
`120.0045` rate and preserves the frame count but NOT the PTS phase, so it removes
only ~0.27 s of the ~1.6 s drift — confirming the phase shift is the dominant term
and a re-encode cannot be made safe.

**Fix — crop is now a display-time slice, never a re-encode.**
- `crop_video.py` writes only the box: `<base>_crop.json` (`{x, y, size}`). No
  ffmpeg encode, no cropped video.
- `make_sync_video.py` always times the ORIGINAL recording (`resolve_paths` no
  longer prefers a cropped file). `load_crop` reads the sidecar (`--no-crop`,
  `--crop-params` overrides); `render_clip(..., crop=box)` passes it to
  `TrimmedFrameSource`, which slices each decoded frame with `crop_frame` before
  display. The timing path is byte-for-byte the uncropped path.
- New in `video/trimcrop.py`: `CropBox`, `crop_params_path`, `write_crop_params`,
  `read_crop_params`, `crop_frame`.
- Verified on 07-27: the cropped render's `probe_rate` is the true 120.0048 and
  its `frame_sess` is identical to the no-crop render; the cropped frame equals
  the numpy slice of the full frame. Tests in `tests/test_trimcrop.py`,
  `test_make_sync_video.py`, `test_crop_video.py`.
- Supersedes `docs/superpowers/specs/2026-07-15-video-crop-tool-design.md`
  (crop-first). Stale `*_cropped.mp4` files are ignored — delete them.

## Still open (follow-ups)

- **This reference file (`ACG-26-3`, 2026-07-13) has no recorded L** and a real
  ~5 s hole in every sensor at `start_time` (permanent data loss — the samples
  were never taken). It predates the fix, so `rec.bookmark_latency` is 0.0 and
  its only alignment lever remains a one-time `--sync-offset` measured from a
  single clearly-visible lick (≈ half the 5 s gap ≈ 2.5 s).
- Threading removes the acquisition stall but the bookmarked frame is still
  grabbed ~one-way-latency after `start_time`; the recorded bracket (fix 2) is
  what makes that residual recoverable, so future recordings still depend on the
  renderer correction (fix 3). If the wireless one-way latency itself can be cut,
  the residual shrinks toward zero.
- The mock client (`hardware/pi_camera_mock.py`) still returns a synthetic
  1-based `frame_index`; it has no sidecar, so `make_sync_video` never runs on
  mock output. Left as-is intentionally.

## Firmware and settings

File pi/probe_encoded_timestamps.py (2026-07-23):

#!/usr/bin/env python3
"""Pi-only probe: what does picamera2 hand to ``Output.outputframe`` per frame?

Run this on the Pi for a few seconds. It records with the SAME config/encoder/
CFR mux as production (``camera_backend`` + ``ffmpeg_output``), but wraps the
output so it captures, for the first N encoded frames, the ``timestamp`` argument
picamera2 passes to ``outputframe`` -- alongside the capture ``SensorTimestamp``
values logged in ``pre_callback`` (what today's ``.txt`` sidecar holds).

It answers the three questions that decide the drop-marking sidecar format:

  1. Is a per-frame ``timestamp`` actually passed (not ``None``)?
  2. Units -- nanoseconds or microseconds?
  3. Same clock as ``SensorTimestamp`` (so ``.encpts.txt`` lines up with the
     existing ``.txt`` sidecar and the bookmark anchor)?

It also prints encoded-vs-captured frame counts and the muxed mp4's frame count,
confirming the encoder drops frames (encoded < captured) and that the mp4 carries
exactly one frame per ``outputframe`` call.

    python3 -m pi.probe_encoded_timestamps            # ~5 s, /tmp/probe.mp4

Nothing here is imported off-Pi (picamera2 only loads in ``main``).
"""
import subprocess
import sys
import time
from pathlib import Path

from pi import ffmpeg_output
from pi.camera_backend import TARGET_FPS, encoder_kwargs, video_config_kwargs

N = 25            # how many encoded frames to print in detail
KEEP_CAP = 400    # how many capture SensorTimestamps to retain for matching
DURATION_S = 5.0
OUT_MP4 = "/tmp/probe.mp4"


def _make_probe_output(stdin):
    """A FileOutput that records the ``timestamp`` picamera2 passes per encoded
    frame. Built inside main so picamera2 imports stay Pi-only."""
    from picamera2.outputs import FileOutput

    class ProbeOutput(FileOutput):
        def __init__(self, fileobj):
            super().__init__(fileobj)
            self.stamps = []   # timestamp arg for the first N encoded frames
            self.count = 0     # total encoded frames (== container frames)

        def outputframe(self, frame, keyframe=True, timestamp=None,
                        *args, **kwargs):
            if self.count < N:
                self.stamps.append(timestamp)
            self.count += 1
            return super().outputframe(frame, keyframe, timestamp,
                                       *args, **kwargs)

    return ProbeOutput(stdin)


def _report(enc_stamps, enc_count, cap_stamps, cap_count, mp4_frames):
    print("\n================ PROBE RESULT ================")
    print(f"encoded (outputframe) frames : {enc_count}")
    print(f"captured (pre_callback) frames: {cap_count}")
    print(f"muxed mp4 frames             : {mp4_frames}")
    if cap_count:
        print(f"encoded/captured ratio       : {enc_count / cap_count:.4f} "
              f"(<1 => encoder dropped {cap_count - enc_count} frames)")

    print("\n--- first encoded-frame timestamps vs capture SensorTimestamps ---")
    ts0 = enc_stamps[0] if enc_stamps else None
    if ts0 is None:
        print("  timestamp is None -> outputframe carries NO per-frame time.")
        print("  => use the encoder-subclass route, not an output wrapper.")
    else:
        print(f"  timestamp type: {type(ts0).__name__}")
    for i in range(min(N, len(enc_stamps))):
        ets = enc_stamps[i]
        cts = cap_stamps[i] if i < len(cap_stamps) else None
        line = f"  [{i:2d}] outputframe={ets!r}"
        if cts is not None:
            line += f"   SensorTimestamp={cts}"
            if isinstance(ets, (int, float)) and ets:
                # unit/clock hints: ns match ~1.0, us match ~1000
                line += f"   cap/out={cts / float(ets):.3f}"
        print(line)

    # Unit/clock heuristic from the whole captured set (robust to ordering).
    nums = [t for t in enc_stamps if isinstance(t, (int, float)) and t]
    if nums and cap_stamps:
        import numpy as np
        e = np.array(nums, dtype=float)
        c = np.array(cap_stamps[:len(nums)], dtype=float)
        for name, scale in (("nanoseconds", 1.0), ("microseconds", 1e3),
                            ("milliseconds", 1e6), ("seconds", 1e9)):
            # does encoded*scale land on a capture SensorTimestamp (ns)?
            diffs = np.min(np.abs(c[:, None] - (e * scale)[None, :]), axis=1)
            med = float(np.median(diffs))
            print(f"  if outputframe is {name:12s}: median match error "
                  f"{med:.0f} ns")
        print("  (the unit with ~0 match error is picamera2's outputframe unit;\n"
              "   a good match also confirms it IS the SensorTimestamp clock.)")
    print("=============================================\n")


def main():
    from picamera2 import Picamera2
    from picamera2.encoders import H264Encoder

    cap_stamps = []
    cap_count = [0]

    picam = Picamera2()
    picam.configure(picam.create_video_configuration(**video_config_kwargs()))

    def on_frame(request):
        cap_count[0] += 1
        if len(cap_stamps) < KEEP_CAP:
            md = request.get_metadata()
            cap_stamps.append(int(md.get("SensorTimestamp", 0)))

    picam.pre_callback = on_frame

    proc = subprocess.Popen(
        ffmpeg_output.ffmpeg_command(OUT_MP4, TARGET_FPS),
        stdin=subprocess.PIPE, stdout=subprocess.DEVNULL,
        stderr=subprocess.DEVNULL)
    out = _make_probe_output(proc.stdin)
    enc = H264Encoder(**encoder_kwargs())

    picam.start_recording(enc, out)
    time.sleep(DURATION_S)
    picam.stop_recording()
    picam.close()
    ffmpeg_output.finish_muxer(proc)

    mp4_frames = -1
    try:
        r = subprocess.run(
            ["ffprobe", "-v", "error", "-select_streams", "v:0",
             "-count_frames", "-show_entries", "stream=nb_read_frames",
             "-of", "csv=p=0", OUT_MP4],
            capture_output=True, text=True)
        mp4_frames = int(r.stdout.strip() or -1)
    except Exception as exc:  # noqa: BLE001 - probe, never fatal
        print(f"(ffprobe frame count failed: {exc})", file=sys.stderr)

    _report(out.stamps, out.count, cap_stamps, cap_count[0], mp4_frames)
    Path(OUT_MP4).unlink(missing_ok=True)


if __name__ == "__main__":
    main()

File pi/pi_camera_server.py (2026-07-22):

"""TCP front-end for the Pi camera server.

Each connection handles a stream of newline-delimited JSON requests. Most
commands return one JSON response line. GET_FILE returns a JSON header line
({"ok": true, "size": N}) followed by exactly N raw file bytes.

Run on the Pi:  python -m pi.pi_camera_server --port 8770 --output-dir ~/clips
"""
import argparse
import logging
import socket
import socketserver
import sys
from pathlib import Path

from pi.server_core import CameraServer
from video import protocol

log = logging.getLogger(__name__)


class _Handler(socketserver.StreamRequestHandler):
    def handle(self):
        server: "_Server" = self.server  # type: ignore[assignment]
        core = server.core
        for raw in self.rfile:
            if not raw.strip():
                continue
            request = protocol.decode_message(raw)
            if request.get("cmd") == protocol.GET_FILE:
                self._send_file(server.output_dir / request.get("name", ""))
                continue
            response = core.handle(request)
            self.wfile.write(protocol.encode_message(response))
            self.wfile.flush()

    def _send_file(self, path: Path):
        if not path.is_file():
            self.wfile.write(protocol.encode_message(
                protocol.make_error(f"no such file: {path.name}")))
            self.wfile.flush()
            return
        size = path.stat().st_size
        self.wfile.write(protocol.encode_message(protocol.make_ok(size=size)))
        with open(path, "rb") as fh:
            while chunk := fh.read(65536):
                self.wfile.write(chunk)
        self.wfile.flush()


class _Server(socketserver.ThreadingTCPServer):
    allow_reuse_address = True
    daemon_threads = True

    def __init__(self, server_address, core: CameraServer, output_dir: Path):
        self.core = core
        self.output_dir = output_dir
        super().__init__(server_address, _Handler)


def serve(core: CameraServer, host: str = "0.0.0.0", port: int = 8770,
          output_dir: str = ".") -> _Server:
    """Create (but do not run) a threaded TCP server bound to host:port."""
    return _Server((host, port), core, Path(output_dir))


def configure_logging(level=logging.INFO):
    """Timestamped logging to stderr.

    Every line is stamped so a failed session can be lined up against the
    desktop's log and the HDF5 timestamps. Run the server through
    pi/run_server.sh: unbuffered output is what makes these lines actually
    reach the log file while the process is still alive.
    """
    logging.basicConfig(
        level=level, stream=sys.stderr,
        format="%(asctime)s %(levelname)s %(name)s: %(message)s",
        datefmt="%Y-%m-%d %H:%M:%S")


def log_network_interfaces():
    """Log every up interface and its addresses at startup.

    The camera link must run over the wired interface. On 2026-07-22 wlan0 came
    back after a reboot (a `rfkill`/UI wifi toggle does not reliably persist),
    associated with a weak guest SSID in the vivarium, and roamed between APs
    every few minutes — each roam tearing down DHCP. A bookmark was refused and
    the session lost its video<->trace anchor. Logging this makes a live wlan0
    obvious in the first line of the log instead of after a lost run.
    """
    try:
        for info in socket.getaddrinfo(socket.gethostname(), None,
                                       proto=socket.IPPROTO_TCP):
            log.info("local address: %s", info[4][0])
    except Exception as exc:  # never block startup on a diagnostic
        log.warning("could not enumerate local addresses: %s", exc)
    try:
        names = [name for _, name in socket.if_nameindex()]
    except Exception as exc:
        log.warning("could not enumerate interfaces: %s", exc)
        return
    log.info("network interfaces: %s", ", ".join(names))
    wireless = [n for n in names if n.startswith(("wlan", "wlp"))]
    if wireless:
        log.warning("wireless interface(s) present: %s. The camera link must "
                    "run over the wired interface; a roaming wifi association "
                    "will drop requests mid-session. Disable with "
                    "'dtoverlay=disable-wifi' in /boot/firmware/config.txt.",
                    ", ".join(wireless))


def main():
    parser = argparse.ArgumentParser(description="CLiQR Pi camera server")
    parser.add_argument("--host", default="0.0.0.0")
    parser.add_argument("--port", type=int, default=8770)
    parser.add_argument("--output-dir", default=".")
    args = parser.parse_args()

    configure_logging()
    from pi.camera_backend import Picamera2Backend
    core = CameraServer(Picamera2Backend(output_dir=args.output_dir))
    server = serve(core, host=args.host, port=args.port, output_dir=args.output_dir)
    # Logged AFTER the bind succeeds: if this line is absent from the log, the
    # socket never came up and every desktop attempt saw "connection refused".
    log.info("listening on %s:%s, output-dir=%s",
             args.host, args.port, args.output_dir)
    log_network_interfaces()
    try:
        server.serve_forever()
    except KeyboardInterrupt:
        pass
    finally:
        log.info("shutting down")
        server.shutdown()
        server.server_close()


if __name__ == "__main__":
    main()

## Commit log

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2026-01-28 Fix FT232H driver installation link in README
    Updated the installation method link for FT232H drivers.
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2026-02-03 Added some error handling to the MATLAB lickDetector.m script, in case volumes or weights are not recorded for some animals.
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2026-02-05 Revise Windows shortcut instructions in README
    Updated instructions for creating a desktop shortcut on Windows to use start_cliqr.bat instead of a PowerShell command.
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2026-06-23 fix: stream GET_FILE body via buffered reader to prevent MP4 corruption
    Refactor fetch_files to use a single buffered reader (socket.makefile("rb"))
    for both header and body reads. Previously, _recv_line would over-read beyond
    the header newline into the file body, causing data loss or corruption on
    large files. The header and body are sent back-to-back on the same socket;
    buffered reader ensures no bytes are lost between reads.
    Also add _recv_file_buffered helper for reading from the buffered stream,
    and a regression test that verifies large files (>4096 bytes) are fetched
    intact when header and body are coalesced.
2026-06-23 fix: correct video-capture docs and run camera I/O off the GUI thread
    - Fix A (DOC): Updated docs/VIDEO_CAPTURE.md to accurately state that the
    current .txt format writes absolute SensorTimestamp nanoseconds (not
    relative), and that compatibility with load_frame_offsets() requires
    pending changes (2-line header + relative ns offsets, relative video_pts
    base). Added "Known limitations / pending work" section noting this is
    deferred to on-device validation. Added TODO comments in camera_backend.py
    (_on_frame and bookmark methods) describing the planned changes.
    - Fix B (I/O non-blocking): Made camera operations non-blocking:
    1. Updated utils/state.py make_camera_client() to acce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
    [camera_backend.py]
2026-06-30 Updated default Pi address to picamera0.local, added new test for threading of the video recording because the thread was dying immediately so the recording silently failed
    [server_core.py]
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2026-07-08 Add framerate bottleneck diagnosis design doc
    Documents the ~20% frame-drop finding on the 120fps Pi camera pipeline
    and the isolation A/B diagnostic plan to locate and fix the bottleneck.
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2026-07-09 Record bottleneck diagnosis results and validated fix
    Software H.264 (no Pi 5 hardware encoder) saturated CPU at 1536x864/120;
    downscaling to 1280x720 at 3 Mbps cut real-pipeline drops from 13-20% to
    0.24% at a stable 119.7 fps.
2026-07-09 Fix board-map drift and frame-offset header skip in false-positive analysis
    Three issues found in review of the false_positive_analysis workflow:
    - SENSOR_BOARD_MAP still hardcoded the retired 4-board rack layout while the
    recorder now writes the 8-board layout, so load_sensor_data/load_lick_times_abs
    raised KeyError (or loaded the wrong sensor) for sensors 4-9 and 13-24. Derive
    the map from utils.state.SERIAL_NUMBER_SENSOR_MAP so it can't drift again.
    - load_frame_offsets used skiprows=2, but pi/camera_backend writes a headerless
    file (one absolute-ns SensorTimestamp per line). It silently dropped the first
    two frames and shifted bookmark-path lick times ~17ms. Read headerless.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
2026-07-09 Release the Pi camera on stop_session so the next session can acquire it
    Root cause of the field bug where the video bookmark failed with "no active
    session" on any recording after the first (without restarting the server):
    stop_session() called stop_recording() but never Picamera2.close(), so the
    previous instance kept the camera device in the Configured state. The next
    start_session()'s Picamera2() then failed to acquire it ("Camera __init__
    sequence did not complete"), leaving no active session, so BOOKMARK returned
    "no active session".
    stop_session now closes the camera (in a finally, so a failing stop_recording
    still releases it), and start_session defensively releases any camera a pri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
    [camera_backend.py]
2026-07-09 Serialize recorder HDF5 access behind a lock
    The periodic buffer flush runs on the recording task while metadata and video
    bookmark writes fire from GUI event handlers on another thread, all opening the
    same HDF5 file r+. Default HDF5 is not thread-safe, so concurrent writes risk
    silent corruption (and, on stricter builds, "unable to lock file" errors).
    Guard every h5py.File open in SensorRecorder with a per-recorder lock so file
    access is serialized. Hardening: the current h5py build tolerates concurrent
    same-process opens without raising, so this is defense-in-depth against the
    non-threadsafe write path rather than a fix for a reproduced crash.
    Adds a concurrency test that hammers the me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
2026-07-09 Only retain the camera client when the Pi session actually starts
    Previously start_recording assigned camera_client before calling start_session
    and left it set (and camera_video_filename stale) when the call failed or timed
    out. That made stop_recording spawn a stop/fetch against a session that never
    started and let a previous session's video filename be written into the next
    recording's HDF5. The 2.0s timeout was also shorter than the client default and
    could time out during the Pi's Picamera2 warmup, misreporting a slow-but-OK
    start as a failure.
    Extract _start_camera(): it clears camera_client/camera_video_filename up front
    and only sets them on an ok response, and uses a generous CAMER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
2026-07-09 Reset per-sensor recording cycle at session start
    sensor_states persist across recording sessions, so recording_cycle carried
    over: a second session (new HDF5 file) wrote its first recording under suffixed
    datasets (start_time1, video_pts1, ...) that false_positive_analysis, which
    reads cycle 0, could not find. Reset each sensor's lifecycle fields (cycle,
    is_recording, status, elapsed, start_time) when a new session starts, preserving
    animal IDs and volume/weight inputs.
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2026-07-09 Turned off autofocus and set lens position to 1000 (to get shortest focus possible)
    [camera_backend.py]
2026-07-09 Add camera test-snapshot for pre-recording alignment check
    Adds a SNAPSHOT command so the operator can grab one still from the Pi
    camera and view it in the GUI, without starting a recording, stopping it,
    and inspecting the video to confirm the camera is aligned.
    - protocol: SNAPSHOT command
    - backend.snapshot(): idle-only; opens a throwaway camera, captures a
    full-FOV still at RECORD_SIZE (framing matches the recorded video),
    releases the device. _capture_jpeg hook keeps it testable off-Pi.
    - server_core: refuses SNAPSHOT while a session is active; base64-wraps
    the JPEG into the one-line JSON reply.
    - client + mock: snapshot() method; mock returns a real 1x1 JPEG.
    - GUI: "Test snapsho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
    [camera_backend.py, server_core.py]
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2026-07-15 Made the bookmark call to the Pi threaded so it doesn't block the entire Solara GUI thread until it's resolved (this was leading to ~5s of capacitance data loss)
    [camera_backend.py]
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2026-07-15 docs: record ffmpeg -ss/-to timeline asymmetry in crop tool spec
    Input -ss is relative to the container's start_time, while -to under
    -copyts is absolute. Verified on the reference recording: a cropped file
    whose PTS start at 30s yields zero frames for -ss 35 and seeks correctly
    for -ss 5. subclip_copy must subtract the input's start PTS, which the
    existing code never had to do because the original video starts at 0.
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2026-07-15 feat: explicit crop origin, stream-copy subclip, start-PTS-aware seek
    trim_and_crop moves to video/trimcrop.py and takes an explicit square
    crop origin instead of hard-coding a center crop. Adds subclip_copy, a
    stream-copy cut used to seek into a long recording without re-encoding,
    and probe_start_pts to support it.
    Input -ss is relative to the container's start_time while -to under
    -copyts is absolute, so subclip_copy subtracts the input's start PTS from
    the seek and leaves the end alone. trim_and_crop reads only the original
    recording, whose PTS start at 0, so it needs no such correction.
2026-07-15 fix: decode trimmed clips passthrough so frames match their PTS
    The Pi footage is variable-frame-rate (coded 240 fps, real ~120).
    imageio's default ffmpeg reader forces constant frame rate and duplicates
    frames to fill the gaps, so its sequential decode yields more frames than
    the clip has PTS entries: 7837 decoded vs 7814 real on a 60 s window of
    the reference recording.
    TrimmedFrameSource counts frames by decode order but times them from the
    ffprobe PTS list, so every duplicate slips the frame-to-session mapping —
    about 0.2 s per 60 s of clip, accumulating with clip length, and silent.
    Decoding with "-vsync 0" passes frames through untouched: exactly one
    decoded frame per PTS entry.
    Fo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
2026-07-15 docs: fix two wrong test values in the crop tool plan
    Task 5's latency test picked a bracket whose midpoint is not exactly
    representable: (110.1+110.3)/2 - 110.0 is 0.19999999999998863, leaving
    video_base_eff a hair above zero, so compute_trim_frames' `sess >= start`
    dropped frame 0 on an epsilon. Use a bracket with an exact 0.25 latency.
    Task 5's empty-window test could never fire: the bookmarked frame sits at
    session time == latency by construction, so [0, duration] always contains
    it. Only a reversed window (stop before start) is actually empty.
    Both surfaced by the Task 5 implementer rather than worked around.
2026-07-15 feat: crop_video CLI core — session window, output path, validation
    Task 5 of the video-crop-tool plan: everything except the GUI, so the
    sync-window math and CLI plumbing are testable headlessly. main() ends
    in raise NotImplementedError("GUI wired up in Task 6") by design —
    Task 6 replaces that line with the matplotlib crop UI.
    compute_crop_window always applies the latency-corrected anchor
    (video_base - bookmark_latency), matching make_sync_video's
    render_clip so the crop tool's trim window and the sync renderer never
    disagree. resolve_paths is called with prefer_cropped=False since this
    tool always operates on the original video.
    Test values corrected per the fixed plan: the latency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
2026-07-15 cleanup: remove dead imports, dedupe sync-anchor formula, fix stale wording
    - make_sync_video.py: drop unused `subprocess` import (trim_and_crop moved to
    video/trimcrop.py) and unused `cropped_path_for` import.
    - crop_video.py: drop unused `TAIL_MARGIN` import (its default now lives
    inside trim_window_seconds).
    - make_sync_video.py: clip_trim_window now returns the latency-corrected
    video_base_eff it built the window from, so render_clip takes that value
    instead of recomputing the identical expression a second time.
    - make_sync_video.py: reword --intermediate help text and the matching print
    line now that this script only trims (crop_video.py owns cropping).
    - tests/test_make_sync_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
2026-07-15 test: guard render_clip's frame-session anchor against latency regression
    The reference recording predates the bookmark-latency bracket (latency
    0.0), so no existing test can distinguish probe_frame_session_times
    being called with the corrected video_base_eff vs. the raw
    rec.video_base — swapping them leaves all 72 tests green while every
    frame's session label runs `latency` seconds early (video ahead of the
    trace). Add a synthetic, nonzero-latency test that monkeypatches
    subclip_copy/probe_frame_session_times/TrimmedFrameSource and asserts
    the corrected anchor reaches the probe call. Widen _synthetic_rec with
    an optional `n` for a renderable trace panel, defaulting to the
    original zeros(3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
2026-07-16 fix: correct bookmark alignment, delete stale renderer, document decisions
    Alignment-review follow-ups (cap<->video sync):
    - Delete video/sync_video.py + test: stale duplicate renderer that still
    carried both already-fixed bugs (CFR frame duplication, no bookmark-latency
    correction). make_sync_video.py/trimcrop.py is the canonical pipeline.
    - alignment_from_bookmark: apply bookmark-latency correction, reusing
    trimcrop.bookmark_latency so the formula can't diverge again. video_start now
    = (start_time + L) - video_pts; L=0 when the host bracket is absent.
    - Document the rejected sipper-in-cap anchoring approach
    (docs/alignment-decisions.md) so we don't revisit it.
    - Add the stop-boo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
2026-07-16 feat: fire stop bookmark on sensor/global stop for drift fit
    bookmark_stop() mirrors the start bookmark on a daemon thread. stop_sensor
    fires it fire-and-forget (camera still active); the global stop path captures
    the thread and joins it before STOP_SESSION so the Pi is bookmarked while its
    session is still live.
2026-07-16 Added stop bookmark to benchmark misalignment over time
    [camera_backend.py]
2026-07-16 Fixed alignment bug that was assuming the network travel time between desktop and Pi was causing misalignment. The root cause was that network travel is very quick, but the Pi is not. So it takes ~4.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
2026-07-17 Fixed 8 board rack layout, sensors had been misnumbered in the board -> sensor map
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2026-07-22 Increased ft232h latency to 2ms because we were getting read errors at 1ms and we don't actually need that fast of a samplerate anyway
2026-07-22 Added guard for if we hit that same communication error with the ft boards, now it only loses a few samples from one board instead of losing the entire run
2026-07-22 Now that we have sampling headroom, increase the number of samples that are averaged on-board on the MPR121s so that we get less noise
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2026-07-22 Trying to fix silent crash on the Pi that stopped a recording at 44 minutes out of the 2 hours
    [camera_backend.py, ffmpeg_output.py, server_core.py]
2026-07-22 Working on ensuring the silent failure doesn't happen with video recording again. Also, it turns out that the Pi had reconnected to WiFi after reboot, so we need to make a note about persisting that 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
    [camera_backend.py, pi_camera_server.py, server_core.py]
2026-07-23 docs: design for session-state persistence + measurement durability
    Root-caused the 07-22 run that recorded capacitance but zeroed all
    volumes/weights and stop_times: Solara stores module-level reactives per
    kernel context, so a mid-run reconnect resets sensor_states to defaults
    while the plain-global recorder keeps sampling. Stop then reads the reset
    store and skips every measurement write.
    Design (Approach A): authoritative plain-global `session` mirrored into the
    per-context reactives, rehydrated on mount; recorder persists measurements
    to the h5 every ~5 min (the >0 guard makes a later reset non-clobbering);
    loud WARNING at stop; HISTORY_SIZE 100 -> 500 for the doubled sample rate.
    Co-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
2026-07-23 feat: route camera writes through set_session
    Camera enable/sensor/host/port/status and disk/stall/video-filename
    writes now persist, so the concurrent-video controls and Start/Stop
    bookmark delivery to the Pi survive a browser refresh.
    Add tests/conftest.py autouse fixture that snapshots/restores the shared
    state.session global per test, since more production paths now write it.
    This exposed a latent bug in test_camera_integration's stop-bookmark
    test (it set the sensor_states reactive but stop_recording reads the
    session global) -- fixed to publish via set_session.
2026-07-24 fix: match multi-cycle video_filename in find_video_sensor
    A Start/Stop restart mid-session writes the video bookmark datasets with a
    cycle suffix (video_filename1, ...), so the exact-match "video_filename in
    group" check failed to locate the video sensor on any restarted recording
    (make_sync_video errored with "no sensor group with 'video_filename'").
    Match video_filename\d* to mirror _resolve_cycle's suffix handling.
2026-07-24 fix: time sync-video frames by real SensorTimestamps, not container PTS
    The Pi muxes the mp4 at a constant -framerate (pi/ffmpeg_output.py), so the
    container PTS are evenly spaced and drift from the real capture clock (~0.1%,
    several seconds over a long session). make_sync_video timed frames by those
    container PTS, so the video slid behind the trace, worse the later in the
    session the clip sat (~2.5 s at ~50 min in).
    Time each trimmed frame by its real SensorTimestamp instead: the container is
    CFR and stream-copied, so a frame's PTS gives its index (round(pts*framerate)),
    which selects the matching sidecar timestamp; the result goes through the same
    clock as the sidecar path so trace and vi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
2026-07-24 feat: mark encoder-dropped frames in a per-frame .encpts.txt sidecar
    Under load the software H.264 encoder drops frames. The capture sidecar logs
    their SensorTimestamps (pre-encode) but the CFR container omits them, so
    container-index and sidecar-line drift apart and the sync residual grows with
    distance from the bookmark (~15-19 frames by ~50 min in).
    Log a SensorTimestamp per ENCODED frame at picamera2's output callback -- one
    line per container frame, so drops are already excluded -- to a companion
    <stem>.encpts.txt, transferred to the desktop and cleaned up alongside the
    video. picamera2 hands outputframe a microsecond time relative to the segment's
    first encoded frame (confirmed by pi/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
    [camera_backend.py, ffmpeg_output.py]
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2026-07-25 docs: spec for bookmark connect-latency fix (cache resolved IPv4 per session)
    Video ran ~25 frames ahead of the trace mid/late session. Root-caused to
    PiCameraClient._request paying a ~2-5s IPv6-link-local connect stall on every
    bookmark (getaddrinfo lists the dead fe80:: address before the working IPv4),
    whose call-to-call variance skews the two-bookmark slope. Fix: resolve once,
    IPv4-first, cache the working address on the client instance.
2026-07-25 fix: cache resolved IPv4 in PiCameraClient to kill dead-IPv6 connect stall
    _request now routes through _connect(): resolve once, sort IPv4 ahead of the
    dead IPv6 link-local, connect with a 0.1s per-address timeout, and cache the
    winning address for the session. Removes the ~2-5s per-bookmark stall whose
    variance skewed the video<->trace slope. Wired-only transport; stale wlan0
    comment corrected.
2026-07-25 fix: route PiCameraClient.fetch_files through cached _connect()
    End-of-session file transfer now shares the IPv4-first cached-address connect
    instead of a second bare create_connection, so it never re-pays the dead-IPv6
    stall.
2026-07-28 fix: correct sync-video framerate drift and constant lead offset
    Two sync-video timing fixes surfaced by the 2026-07-27 ACG-26-3 run:
    1. probe_frame_rate read ffprobe r_frame_rate (120/1), but the Pi
    container is CFR at the true 120.0048 fps (avg_frame_rate). The
    round(pts*rate) ordinal recovery in probe_frame_session_times drifted
    ~1 frame per 25k frames, reaching ~33 frames (0.27 s) by the end of a
    2-hour recording and dragging the video ahead of the trace worse the
    later the clip. Use avg_frame_rate (exact for CFR), fall back to
    r_frame_rate only when unavailable.
    2. A constant ~2-frame (16.667 ms) residual video-lead survived the
    latency + drift corrections, identi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
2026-07-28 fix: crop sync-video at display time instead of re-encoding
    Cropping the mouse video by re-encoding (crop_video -> _cropped.mp4, then
    make_sync_video times that file) drifted the video ~1.6 s late against the
    trace on a late clip. Re-encoding to apply the crop filter regenerates the
    presentation timestamps onto a fresh CFR grid: wrong phase (frame pts_time no
    longer lands on the original frame grid) and wrong rate (avg_frame_rate reset
    from the true ~120.0048 fps to a flat 120/1). probe_frame_session_times recovers
    each frame's original container ordinal via round(pts_time * rate) to index the
    per-frame SensorTimestamp array, so both errors corrupt the lookup. The uncropped
    path never re-enc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
2026-07-29 fix(ml): harden resample against absolute-epoch float cancellation
    Gate-2 end-to-end validation (Python cascade vs MATLAB detectLicksFromRaw) on an
    old-scale recording revealed ~4% disagreement traced to np.arange grid drift at
    Unix-epoch magnitude (~1.7e9): 0.01s steps lose precision, shifting the 100Hz grid
    by up to ~1 sample and flipping borderline detections. Build the grid relative to
    t0 instead. validate_recording also zero-bases time (mirroring filter_data). Gate 2
    now 219/219 matched, precision/recall 1.0.
2026-07-29 feat(ml): bootstrap driver — build training set from results_combined h5
    Walks <animal>/<session>/{cap_data,time_data,lick_times} in a combined results
    file, runs bootstrap_segments per animal-session (threshold licks as seed), skips
    controls, and writes one training h5 with per-segment source provenance for later
    session-level split.
2026-07-29 feat(ml): interactive Panel labeler — clickable trace + file browser
    Rework the labeler from a static Solara/matplotlib view (which could not receive
    clicks) into a Panel app backed by a Bokeh server, so the trace is genuinely
    interactive: click to add a lick at the nearest sample, click near one to select
    it, Remove and Nudge +/-1 act on the selected lick. Adds a FileSelector to browse
    to the training .h5 instead of typing a path. Pure edit logic (add/select/remove/
    nudge/recompute-label) moved to labeler/logic.py and unit-tested (9 tests). No new
    dependency — Panel/bokeh already ship with the project.
    Run: panel serve ml_detection/labeler/app.py --show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
2026-07-29 fix(ml): make labeler self-locating so panel serve finds ml_detection
    panel serve execs app.py without the repo root on sys.path -> ModuleNotFoundError
    -> blank page. Add the repo root (three dirs up from this file) to sys.path before
    importing the package. Verified in-browser: renders, file browser lists the h5,
    Load draws the trace, clicking adds a lick marker.
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2026-07-30 feat(ml): gate-3 fine-tune driver + fix labeler double-_curated save
    - scripts/finetune_from_labeled.py: fine-tune on curated labels. Recovers per-segment
    session provenance by index from the original bootstrap file (labeler preserves order
    but save_training_h5 drops the source dataset), splits by whole session, reuses
    train.fine_tune, reports held-out bout/point precision/recall/F1.
    - Labeler Save strips existing _curated suffixes so re-saving a curated file overwrites
    <name>_curated.h5 instead of piling up _curated_curated.h5.
    - Commit the fine-tuned checkpoint so algorithm='ml' uses the new-scale model.
    Held-out F1: bout 0.978, point (per-sample) 0.759.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
2026-07-30 feat(ml): class-weighted point-net fine-tuning lifts per-lick recall 0.75->0.93
    Point-net lick-center samples are a small minority, so plain cross-entropy +
    accuracy-monitored early stopping produced a conservative net (per-lick recall 0.745).
    Fix: inverse-frequency class weights, monitor positive-class F1 (not accuracy), and
    80 point epochs (was 20). Held-out per-lick: P 0.974, R 0.934, F1 0.954 (was
    0.980/0.745/0.847). Bout net unchanged (F1 0.978). Retrained finetuned.pt committed.
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2026-08-12 Removed the optimal threshold comparison and swapped the Example data for a newer session with the better dynamic range
    [SensorMap.xlsx, TimeFix.xlsx, layout.csv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]
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
